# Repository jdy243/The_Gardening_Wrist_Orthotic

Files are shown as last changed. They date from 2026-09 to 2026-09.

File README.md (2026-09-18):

# The Gardening Wrist Orthotic

A student designed product for people whose wrist or joint pain gets in the way of gardening. Featuring a 3D-printed customized wrist brace and gardening glove. The brace supports the wrist and forearm, and a quick-release clip on the palm lets a hand tool click into place instead of having to be gripped. This Project was nominated & presented at the Buckeye Engineering Design Showcase, April 28, 2026, Ohio Stadium.
<br>
<br>

<p align="center">
  
</p>

<p align="center">Buckeye Engineering Design Showcase, April 28, 2026, Ohio Stadium.</p>

## Final Design
- [Physical Design Overview](https://github.com/user-attachments/assets/03434787-c6b2-4d2d-ab97-b5e6720f0fb0)
- [3D Model of the Brace](https://sketchfab.com/models/580d400f9824445db32a312051443653/embed?autostart=1)
- [3D Model of the Quick Release System (Adapter)](https://sketchfab.com/models/04e7fd2b0e794eb98720fba45b6b7ad8/embed)
- [3D Model of the Quick Release System (Base Plate)](https://sketchfab.com/models/98bdad573c1f4930803acb94b18789f5/embed)

### The problem

Weeding, digging, and turning soil put real strain on the wrist and forearm, especially for gardeners with arthritis or other joint pain. Most existing products only solve part of this: a wrist stabilizer supports the joint but doesn't help with gripping a tool, and compression gloves or ergonomic tool handles don't address wrist overextension. Products that do both tend to be expensive or bulky.

#### How it works

The brace is CADed based on the surface details from a user's hand model from a LiDAR scan, and later 3D printed in 95A TPU so it's shaped to that hand rather than a generic size. It's sewn onto a standard gardening glove and closes around the wrist with Velcro straps. A slot-clip printed into the palm of the glove locks onto a matching clip on an adjustable Velcro strap that wraps around a tool's handle, so the tool stays attached without needing a tight grip. All 3D-printed parts use hexagonal cutouts and a gyroid infill to keep weight down without giving up strength.

### Specifications

| Metric | Value |
| --- | --- |
| Total weight | 0.55 lb (254 g) |
| Load-bearing capacity | tested to 25 lb |
| Wrist flex range | 0-90 degrees (overextension blocked) |
| Time to put on / take off | 8.65 s (target under 50 s) |
| Time to attach or detach a tool | 4.3 s (target under 40 s) |
| Material cost per unit | $14.83 |

### The Team

Team N, ENGR 1182.01, The Ohio State University, advised by Professor Jergens.

- Jonathan Yang
- Riya Shankar
- Nicholas Farley
- Dawson McMurry

Presented at the Buckeye Engineering Design Showcase, April 28, 2026, Ohio Stadium.

# Repository contents

- [Technical Design Review](docs/Technical-Design-Review.pdf) — the full project report, covering problem definition, user research, concept development, prototyping, and testing.
- [Poster](media/Poster.jpg) — the showcase poster.

This repository currently holds the written documentation and poster. CAD files/3D-print file are on an alternative website; if you need them, you can download them though the 'Final Design' portion in README.

## License

No license file is included yet. Since this is a four-person team project.

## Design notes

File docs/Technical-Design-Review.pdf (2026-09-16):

# Gardening

# Wrist Orthotic

## Team N

### Riya Shankar

### Nicholas Farley

### Jonathan Yang

### Dawson McMurry

## ENGR 1182.01 7440

## Professor Jergens

## April 19, 2026

## Table of Contents

## Executive Summary

## Problem Definition Review

### 1. Introduction

Chronic and temporary joint pain affects a large demographic of people around the world. It stops individuals from participating in hobbies and activities of personal enjoyment and increases their intake of medication for pain relief. All members of Team N were tasked with interviewing an individual about frustrations they may encounter in their daily lives; some of their pains included poor house heating, laptop battery life, lower-back mobility issues, and joint pain while gardening. In this project, Team N has decided to address this problem for individuals who garden, whether professionally or as a hobby, and create a wrist orthotic device to stabilize the wrist and remain adaptable for gardening purposes.

The team has researched the demographic most affected by joint pain, the main contributors to such pain especially in the upper limbs, and alternative products on the market that are targeted toward solving the team’s chosen problem. The team created a graphical user persona to mimic the target audience of the project’s final product to solidify the intended users, and therefore also determine the most significant factors the team must take into consideration during the product brainstorming process. The team then compared alternative products to their own idea using informational graphics and charts and determined the user needs, factors, and costs required to create this product and ensure its effectiveness surpasses those of the alternatives.

During the brainstorming process, the team created three concept designs for the final product. The team considered the most effective methods of designing and creating the product, taking items like materials, budget, and user needs as the highest priorities. The team also received feedback from other teams to finalize the concept plan for the orthosis. The wrist orthosis will contain a brace around the forearm, wrist, and palm, and will be customized to each user using modeling software. A gardening glove with flexible support plates through the backhand and fingers will be attached to the brace, allowing users to garden comfortably. A quick release plate will be sewn onto the palm of the glove to correspond with another plate attached to an elastic band that can be put on the handle of hand shovels and small gardening tools. The plates will click and attach to provide the user with a firmer grip upon the tool and subsequently further relief on the wrist and joints.

### 2. Problem Definition

The problem the team aims to address is the lack of accessible assistive devices that allow individuals with joint pain to garden comfortably and safely. The team is exploring the design of an orthosis or similar product intended to reduce pain and strain during gardening activities. The selected user group includes individuals with upper-body joint pain and mobility limitations, caused by either chronic or temporary illness and injury.

a. User Persona

Figure 1 depicts the team’s user persona, named Riley Thomas, who represents a potential individual within the team’s selected target audience. Riley is a 65-year-old Caucasian American woman who lives with her husband in a suburban neighborhood. She has a college education, is currently retired, and frequently gardens in her front and backyard. She has arthritis that especially affects her wrists, elbows, and shoulders, and she often takes medication for pain relief although the medication may have long term effects on her body.

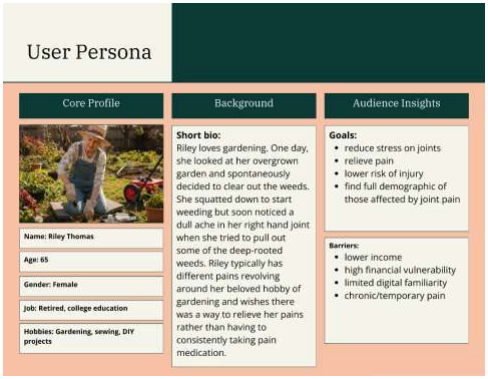
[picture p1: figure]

Figure 1. Graphical User Persona

Riley loves gardening. One day, she looked at her overgrown garden and spontaneously decided to clear out the weeds. She squatted down to start weeding but soon noticed a dull ache in her right hand joint when she tried to pull out some of the deep-rooted weeds. Riley typically has different pains revolving around her beloved hobby of gardening and wishes there was a way to relieve her pains.

b. Tasks and Pains

The selected user group has a considerable number of tasks and pains associated with gardening while affected by joint pain. Common gardening tasks include weeding and planting on the ground, forcing individuals to bend and rest on their limbs often. Additionally, digging and turning soil requires the use of heavy tools and repetitive motions that can strain arm joints and may require often taking medicine to relieve pain.

- Task: Weeding and planting

- Pain: It requires constant, forceful, use of hands and forearms.
- Pain: It often requires resting on the arms and elbows.
- Pain: It is difficult to reach the roots of the weeds buried in the soil.
- Pain: It is often necessary to take many breaks and take pain relief medication.
- Task: Digging and turning soil
- Pain: Using shovels can put severe strain on the arms.
- Pain: Can cause tendonitis & carpal tunnel syndrome from gripping tools tightly.
- Pain: Can strain the rotor cuff due to repetitive actions.

### 3. Research Plan

The goal of conducting research is to gain an understanding of what the most common factors of joint paint and mobility issue plague individuals to have a basis for the anatomical nature of the team’s product. Another goal of the team’s research is to learn how to design such a product, particularly using three-dimensional modeling software, what materials are needed to build the product, and how the product can be more efficient compared to other similar products in the market. An ethical consideration the team discussed was the environmental concerns that come with using plastic for the basis of the product, and the team’s solution to this is using recyclable filament during the 3D printing process.

Table 1. Research Plan Table

Research Question | Qualitative Data Collection | Quantitative Data Collection
(RQ1.1) Which upper-body joints or anatomical parts are largely affected by joint pain? (RQ1.2) What is the demographic of those affected by joint pain? | Online research paper of pain mapping for common shoulder disorders [1]. | Online article of a survey study of upper limb pain and disability among university students [2]. Online research article the changing profile of joint disorders with age [3].
(RQ2) What are the common tasks and pains associated with gardening? | Online article and study that characterizes gardening tasks and corresponding body positions done by older adults. [4] | Online research article on hand discomfort among gardeners. [5]

(RQ3) What are orthoses and how do they provide structural support? | Online article covering how different orthotic devices or orthoses are created and used to benefit the users whether they are stabilizing or preventing injury. [6] Online article that lists and explains the different strategies and components in making an orthotic/prosthetic device. [7, 22] | Online article representing the results of a survey where participants were prescribed an orthotic device in which the average score of the participants satisfaction of the device was 4.53/5. [8]
(RQ4) How can 3D modeling be used to create a product? | Online article comparing traditional and additive manufacturing processes and how 3D printing offers potential in developing orthotic devices [9]. | Online article showing the effectiveness and quick fabrication process of 3D printed orthotics and prostheses in canine, proving the viability of these products in the medical field [10]. Online research article showing how effectively utilizing CAD and 3D printing technology can manufacture smaller and lighter medical products [11].
(RQ5) What are some other similar products that solve this problem, and how can our product be more efficient? | Online research paper on improving gardening for people with arthritis. [12] | Online conference paper covering orthotic prototypes for patients with osteoarthritis, chronic joint pain. [13]

### 4. Research Results

a. Creating User Value

Pains

Gardening is undoubtedly a taxing process on your joints, making it harder for some older or injury-prone people to grip tools and have a proper range of motion for the activity. Some orthotic prototypes have already been developed such as an ergonomic chair [12], yet these solutions are big and unpractical in everyday, gardening use. Researchers analyzed a group of older gardeners, after performing seventeen different common garden tasks, over ten different pains were observed, demonstrating the risk and damage caused by the consistent, scooping, bending, and stretching of the joints and ligaments during gardening [4].

- Using shovels can put severe strain on the arms.
- It can cause tendonitis & carpal tunnel syndrome from gripping tools tightly.
- It can strain the rotor cuff due to repetitive actions.
- Gardening requires constant movement, getting up and down, and frequently resting on elbows
- Can lead to pulled and torn muscles in the arms

Gains

Different 3D printing processes can allow manufacturers and the team to construct different orthotic devices at a quicker pace at a lower cost. It can allow the team to create a model where the team can print 3D parts with different types of filaments that can be changed for different needs. Such as carbon fiber laced filament for durability or TPU for parts that need to be flexible. [9].

- More efficient
- Will take less time and effort to pull weeds out of the ground
- Lower consumption of pain medication
- Rely less on pain medication, reducing their spending
- More cost effective (user only needs one tool instead of multiple shovels, etc.)
- The device will be cheaper than other orthotics on the market
- Adaptive; can change the tools out
- Users can attach gardening tools that can be interchanged on the device

User Needs

Orthotic devices help the users' needs of reducing pain and having a lower risk of injury by allowing the joints, muscles, and bones to be more structurally sound and stable [6]. The overall goal of this device is to aid and target users with joint pain, ensuring several design requirements/categories are met (cost, pain reduction, etc.). For example, pivoting the orthotic device in a 3D printing direction not only makes production faster, but it is cheaper and more adaptive. Additionally, with recyclable filaments, an eco-friendly approach to orthotics could also be explored [10].

- Performance Efficiency
- Pain Reduction
- Lower Risk of Injury

- Cost-effective
- Adaptive
- Comfortability
- Durability

Pairwise Comparison Chart

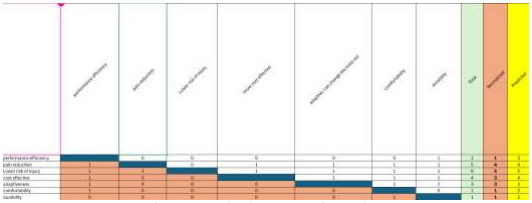
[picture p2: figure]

Figure. 2. Pairwise Comparison Chart

With any design process, some users need to become more redundant over time as design focus shifts from idea to idea. As shown by the above comparison chart, needs such as efficiency and durability were only preferred by the team once over other categories, while needs such as pain reduction and injury prevention were more heavily prioritized in the team’s brainstorming and development process [14]. While searching for other orthotic devices, the team noticed that most wrist-hand orthotic devices also couldn’t balance certain needs when designing, including more commonly cost versus durability and effectiveness. With this as the team’s priority, some sacrifices to the final prototype may need to be made, however it is a matter of balancing the needs than homing in on only a few needs [25].

b. Market Character

Stakeholders

- Medical Orthotic Companies
- These companies could invest in these orthotic products, possibly being able to work with the team to bring these devices to a wider market.
- Urgent Cares/Medical Centers
- These facilities could buy and distribute them to patients in need when properly consulted by a physician.
- Medical Stores/Pharmacies
- The team can easily sell and distribute these products nationwide through stores like CVS, Walgreens, etc.

Market Size

The global market for wrist-hand orthotics is already growing at a rapid rate, currently sitting at around 1.8 billion USD in market cap, with a projected 3.1 billion USD market cap by 2033 [14]. Additionally, Wrist Supports Market size was valued at USD 1.5 Billion in 2024 and is forecasted to grow at a CAGR of 7.2% from 2026 to 2033, reaching USD 2.8 Billion by 2033 [15]. With a growing market, there are more target users. The team’s device will be used by general wrist-hand orthotic patients but mainly targets users who want to work hands-on, in this case gardening, with their orthotics. The main idea for the team’s device is to allow users to complete their daily tasks without unbearable joint pain and with the associated attachable tools, hands-on activities like gardening/weeding are performed with ease.

Current Alternatives

- Strap Wrench: Tool that uses a rubber or nylon strap, typically 12–18 inches long, to grip smooth, polished, or irregular surfaces [20]
- Twist Jar Opener: A handheld or automatic kitchen tool designed to easily remove jar lids that are stuck or stubborn [19]
- ACE Carpal Tunnel Wrist Stabilizer: Wrist brace; “Stabilizer helps relieve symptoms associated with Carpal Tunnel Syndrome with superior, stabilizing support” [18]
- IMAK Compression Gloves: Specialized gloves designed to relieve hand pain, stiffness, and swelling associated with arthritis and poor circulation by tightening around the joint [23]
- PenAgain: Ergonomic pen; “This wishbone-shaped writing utensil is designed for those with carpel tunnel, arthritis, and anyone with a weak grip or limited grasp. It allows the pressure of the natural weight of your hand, rather than your grip, to guide the writing instrument.” [21]
- Paexo Wrist: Mechanical skeleton brace; “Paexo Wrist provides effective support for your wrist when handling loads. The exoskeleton was derived by Ottobock Industrials from a medical device that was specially developed for the treatment of wrist inflammation.” [17]
- Daiya Wrist Exoskeleton: “The Daiya wrist exoskeleton increases support to your wrist during load and tools handling. Its thin aluminum support adjusts the level of wrist fixation in stages to reduce pressure, and three pockets containing aluminum supports on the back and palm of the hand allow the user to adjust the level of fixation.” [25]

- Stainless Steel Tongs: Multipurpose tongs: “Stainless steel construction: these tongs feature a high quality, 430-stainless steel frame” [24]

Figure. 3. Current Alternatives Comparison Chart

Some gaps that the team noticed between the current alternatives are that many of them focus on being cost effective while sacrificing other important aspects such as durability and adaptiveness. The team concluded that the goal would be to try to create a device or product that includes most, if not all, of these attributes to ensure that the product will remain a reasonable price while also allowing it to be durable and adaptive for different uses.

In a survey conducted in 1997, about 30% of the respondents indicated “chronic upper extremity pain associated with physical impairment” [1]. Participants who experienced such pain were a demographic consisting of both men and women of ages 25 to 74 who were randomly selected, and were likely to be blue collar workers, long-term absentees, and current or former absentees. In corroboration with this source, another study conducted in 2019 resulted in a 24% respondent rate of the prevalence of upper limb pain [2]. This study’s subjects were university students between the ages of 18 to 28 where most subjects had been using smartphones for more than 5 years. The results of both studies show that chronic and temporary upper limb pain and discomfort are prevalent across a large demographic, and therefore the team’s decided target audience has not been limited to constricting age, gender, or ethnic range.

Hand tools, such as spades, shovels, sickles, and rakes, are commonly used by gardeners during activities. The excessive use of such tools is often followed by pain or discomfort in gardeners’ hands and forearm regions. Manual work such as gardening requires repetitive movements and can cause high muscular discomfort and strain injuries in the upper limbs due to forearm muscle strain and poor wrist posture. Findings of a 2024 study unveiled that majority of respondents found gardening hand tools to have low to moderate comfort, and there was an increase in pain and discomfort in the hands while using such tools which in turn interfered with their gardening performance [5].

An article published in 2022 showed that traditional orthotics/support devices (such as the spinal cord injury orthotics in this article) are usually made of plaster, and the advent of low-temperature thermoplastic sheets make the finished products bulky, time-consuming (1 week) and expensive [11]. At the same time, due to the limitations of the manufacturing process, their appearance is difficult to make aesthetically pleasing, and their geometric defects also lead to a lack of personalized comfort and functionality. However, by using 3D printing technology, people can design structures that are difficult to make by hand and have extremely high precision. Another study also showed that compared with traditional manufacturing methods, 3D printing technology can produce an orthotics/support device with personalized customization in terms of fitness and shape in one day, thus providing patients with a more economical, comfortable and personalized product [10]. Additionally, a study focuses on customized orthotics/prostheses also showed that it takes less than 6.5 hours to manufacture a 3D printed personal orthotics using PLA Material on a fused deposition modeling (FDM) machine, and the average operation time is only 10-15 minutes. Compared to traditional methods, the time required to fabricate orthotics for patients using 3D printing technology will be significantly shorter [9].

### 5. Value Proposition

The team’s proposed solution to address the problem of joint paint and mobility issues is designing a supportive brace or glove that can lower the user’s pain level. The product is specifically designed for gardening purposes, with the ability to attach tools to the brace that can help users easily weed and plant their gardens. The target end users are individuals over the age of 18 who suffer from temporary or chronic join pain specifically in the wrists. Since race or gender do not seem to define the demographic of those affected by joint pain [2] but typically adults or older aged individuals find themselves to be more affected [3] [4]. The team has decided to focus on developing the product for those in the age range of 18 and above. Users of this device will experience reduced joint pain and can swap out tools on their device, making strenuous tasks like shoveling or gardening less likely to inflict lasting injuries or pain. Being that this device is 3D printing allows it to be a cost-effective option for users, preventing unbearable joint pain without breaking the bank. With the growing market in these wrist-hand orthotics expecting to double in some regions by 2033 [14], this device will likely be revolutionary, all-in-one for those who want to be active without the worry of serious injury and pain.

### 6. Design Focus

The team has discussed and concluded that when it comes to the overall design of the brace, the team wants the product to be comfortable for the user. As a result, the team decided that the best options for securing the brace to the user would either be a Velcro type of function to ensure that the product will stay attached to the user comfortably without it pinching too tight or being too loose. Additionally, the team debated on including a feature of convenience such as utilizing a magnetic plate or an area with different straps that allow users to have easy access to different gardening tools without having to often bend to reach the ground or crowd their hands and pockets.

The team decided that the easiest way to design the product is through the Computer Aided Design (CAD) software. The team intends to produce the final product by 3D printing the base structure with filament, as the variety of filaments that can be used can be determined in context of the products need to be more flexible or durable [11]. These components can also help with the user needs the team identified because filament is environmentally friendly as it can be recycled and additionally, it can typically be stretched out for long distances for a cheaper price, allowing the team to market the product at a more cost-effective standpoint while remaining effective for use.

## Concept Development Review

### 7. Concept Brainstorming and Ideation

a. Process Description

When brainstorming new ideas for the design, the primary method for finding new design options was to research other orthotics, take inspiration from other protypes and designs, and rework them to fit the gardening orthotic. Another important factor when brainstorming is fitting user needs. When an idea is brought to the team, it is evaluated for how it applies to all the user’s needs. Big factors like cost, pain reduction, and injury prevention are focused during this process with other needs being secondary but still vital for the final design. Overall, the main process for the team’s concept of brainstorming is to research and compare user needs, finding the most viable and safe option for its users.

b. Brainstorming Results

The team concluded from brainstorming that the final product would focus on pain reduction and adaptiveness and therefore would include a kind of magnet or strap on the palm of the orthosis to attach different gardening tools to the structure. One possible idea discussed for this detail was 3D printing a quick-release clip slot sewn or in some way attached to the palm of the orthosis glove and additionally create a strap with a slotting piece that could be wrapped around any tool. The slotting piece could be inserted into the clip slot on the glove, allowing the user to gain a firm grip on the tool while being able to easily remove the tool. The team discussed methods that could be used to adjust the sizing of the orthosis, such as Velcro, string, or a quick lacing system using turn knobs. The team decided that the lacing system would be rather difficult to implement and deemed Velcro the better solution. For the base structure of the orthosis, the team considered using a fabric compression glove for the palm and fingers and utilizing 3D printing for the wrist brace structure, which could be customized to the user using an online modeling software such as Lidar Scan.

### 8. Concept Selection

a. Down-Selecting to Two Concepts

Through the team’s discussions with other teams, the team was able to pick two final concepts as to what the team’s product would include. Many of the other teams liked the idea of a quick-release plate for adaptability as well as the team’s idea of how the team was going to secure the device on the user. The two remaining concepts (concept 1 and
2) were selected because both included useful and worthy additions. For the team’s final product, students will most likely combine the best aspects from both concepts to achieve the best overall product.
b. Pugh Scoring Matrix

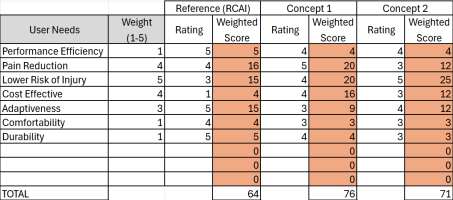
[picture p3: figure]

Figure. 4. Pugh Scoring Matrix Chart

These results show that the reference design (RCAI Wrist Orthotic), while being superior in some categories, struggled to meet user needs like cost effectiveness and lower risk of injury, two important user needs for the final design. The two concepts, however, are far superior in terms of price relying on 3-D printed materials and fabrics and focus more on preventing further injury by providing ample support to the wrist and possibly finger joints. Unfortunately, due to the restrictive durability range of TPU filaments, the prototype will most likely be less durable than the reference orthotic, however being that durability isn’t as important for the final design, these small flaws can be overlooked for the most part as the team focuses its design on effectiveness and cost.

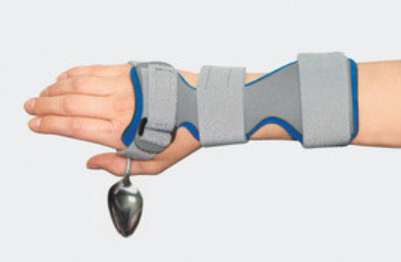
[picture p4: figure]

Figure 5. RCAI Wrist Drop Orthosis [26].

c. Final Concept Selection

The final concept selection will not be based on a specific concept, but rather on combining the advantages of both Concept 1 and Concept 2 due to them both scoring a similar score (5-point difference). Both designs have some drawbacks. For example, the complex locking design of Concept 2 will lead to increased costs, while the installation tooling method of Concept 1 is not as efficient as that of Concept 2. This will allow the team to create the most efficient product by combining the best aspects of our previous sketches, resulting in a product that should be able to fit most the user’s needs.

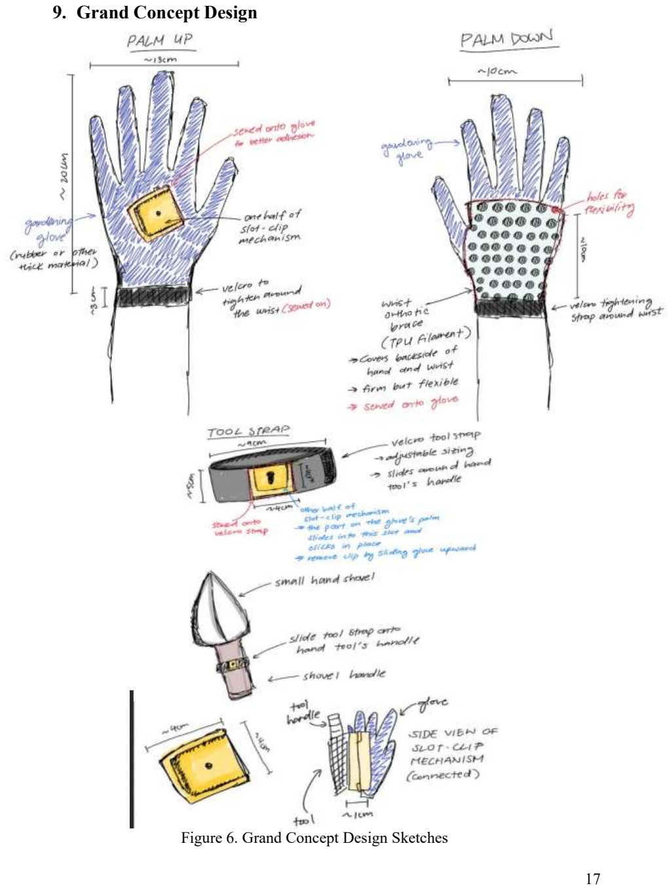
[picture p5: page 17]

### 9. Grand Concept Design

Figure 6. Grand Concept Design Sketches

The grand concept design of the team’s product is a wrist orthosis that consists of a fitted brace (green brace with cutouts) for the forearm and wrist, a glove with thin metal supports running through the seams (dark blue glove), an attached clip on the palm of the glove, and an elastic band with the other half of the clip (pink band) that acts as a slotting mechanism. For demonstration purposes, the team has created a mockup cardboard shovel to show how the elastic band would be able to slide onto the handle of a small hand shovel.

The user would interact with this design by inserting their hand into the brace and glove, with the glove resting underneath the brace structure. The glove provides support to the wrist as it has strips of metal running through pockets on the inside of the glove. These supports are located on the backside of the glove. The brace will be fitted to the user using 3D modeling and will provide tight, secure support to the forearm and wrist. The elastic band will slide over the handle of a small hand shovel or tool. The clip on the elastic band will slot into the clip on the palm of the orthosis and stay in place. The user will be able to remove the clips from each other by pulling upward on the elastic-band clip, releasing it from the slot. The size of the design would be approximately big enough for an adult forearm. The team’s intention with this product is to customize it personally to each user rather than utilize one-size-fits-all dimensioning. For this concept, the orthosis is modeled for a young adult male.

The features that make this design unique are the adaptability of its usage. The elastic band can be fitted onto many hand tools besides gardening tools, and the brace will provide support regardless of whether the user is using the product for a task or simply providing pain relief and compression. The anticipated challenges of developing this idea into a fully realized product are ensuring the comfortability and practicality of the design. As the team’s priorities include efficiency, a challenge would be to ensure that the metal support strips do not prod the user’s skin and provide support without breaking easily, remaining comfortable on the user’s skin.

Additionally, another anticipated challenge is ensuring the clip can support the weight of a hand shovel. To confirm its viability and to gain traction in the market, the design must be versatile as this was the most common value that other products on the market lacked. To prove this, the elastic band must be able to fit over a variety of hand tools besides gardening tools, and the clip must work to secure the orthosis to the elastic band in each case. The product must also be able to relieve users’ pain by means of support and compression across the palm, wrist, and forearm as this is the best way to test its effectiveness.

### 10. Prototyping Design

a. Description of Prototype

Team N plans to design and create a fully functional wrist orthotic for those who are active with hand tools and gardening instruments, reducing joint pain and preventing further injury. The brace is created based on a Surface scan (LiDAR) of a real human hand [27]. This orthotic will slip on like a glove with a rigid, weight-bearing 3D-printed support (brace) that hugs the back of the hand; this will be sewn on to provide better durability. To wear it, the user will insert their hand into the gardening glove through the pinky-finger side of the glove; the user can close the side of the glove using a Velcro strip that runs along that side of the glove. The orthotic can then be secured using Velcro straps located at the wrist, ensuring the glove will not slip off ensuring use. In addition, a 3D-printed slot-clip is sewn into the palm of the orthosis and using a provided tool clip strap, a second slot-clip can be placed on most gardening/hand tools using an adjustable Velcro strap. When slotted into each other, the tool becomes fully fastened to the orthotic meaning the user doesn't need to strain their finger and wrist joints when gripping the tool and with the rigid support on the back of the glove, overextension of the wrist is prevented. When prototyping, budgeting and meeting our user’s needs leads to the biggest limitations, scaling down previous ideas and overall simplifying the team’s concept, however, with the access to 3D printers, Team N can explore more complex support designs and mechanisms allowing for design complexity at a low budget. Team N intends to use OSU’s EED store to order parts such as Velcro and 3D prints and use OnShape to model testing of the orthotic.

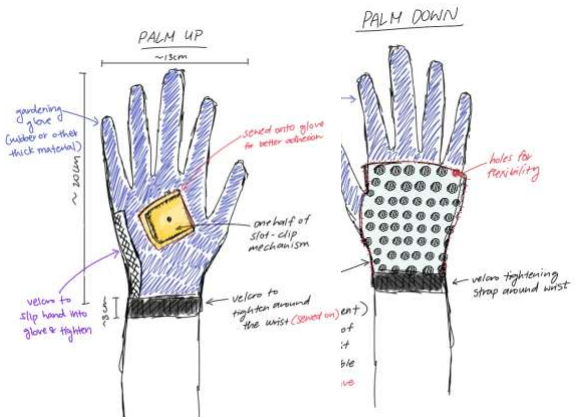
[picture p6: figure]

Figure 7. Wrist Orthosis Prototype Sketches

Figure 8. Slot-Clip Mechanism and Demonstration Sketches

b. Prototype Design Requirements
Design Requirement | Range of Values | Ideal Value | Design Process | Correlating User Needs
Time taken to put orthosis on | 20-50 seconds | 20 seconds | Test ease of putting on and taking off the orthosis during design process | Adaptiveness
Holds tools up to 10 pounds | 1-10 lbs. | 10 lbs. | Attach weights and test durability | Durability, Performance Efficiency
Prevents over-extension of wrist | Wrist can flex 0-90 degrees | Doesn’t extend past 90 degrees | Consistently try on prototype and check wrist flexibility | Pain Reduction, Lower Risk of Injury

Fast slot-clip mechanism | 10-40 seconds | 10 seconds | Time how long it takes, change sizing of parts if necessary for smoother process | Performance Efficiency, Adaptiveness
Low weight | 1-2 lbs | >1.5 lbs | Consistently weigh the prototype | Cost Effective, Comfortability
c. Testing Methodology and Verification Plan

To properly test and verify the design requirements for the prototype, a series of different strength, durability, and logical tests will be performed. To start, a simple load bearing test will be performed on the clip, the team wants to ensure that the quick-release system can hold up to 10 pounds of additional weight without slipping or breaking. To do this, the team will attach different weights (ex. dumbbell) to the quick-release system starting at 2.5 pounds and increasing up to 10 pounds to gradually stress testing the entire system. This process will repeat three times. Additionally, during all three testing processes, students will try to observe (ex. sound) and inspect for deformations or weak points within the system as testing occurs to ensure durability remains constant.

With the gardening wrist orthotic remains on, the team will also ask the user to bend their wrist back and forth to ensure the grading glove braces their wrist and prevents it from overextending or bending, which helps to prevent further injuries. The user will repeat this process five times to ensure its reliability and efficacy. These trials will be measured using a protractor, measuring the wrists’ angle and seeing at what point it stops. Additionally, the gardening wrist orthotic will be weighed to ensure it remains lightweight, targeting under 1.5 pounds to avoid additional force on the user’s joints.

Next, the orthotic will then be tested for ease of use and transfer on and off the user’s hand. Using Team N members, each member will be timed for how long it takes to get the gardening wrist orthotic on and off from their hand, as well as how long it takes to attach and detach the tool onto the quick-release system’s adapter. They will each be timed three separate times with their times averaged, with the team targeting a 10-second average. This is done to make sure the device is easy and adaptable to almost all users, making it a more accessible product to a broader market.

Finally, when finalizing the gardening glove, the team will create and manage a budget to ensure that the orthotic is cheap and efficient to make, utilizing processes such as 3D printing and minimizing materials for a cheaper and simpler design.

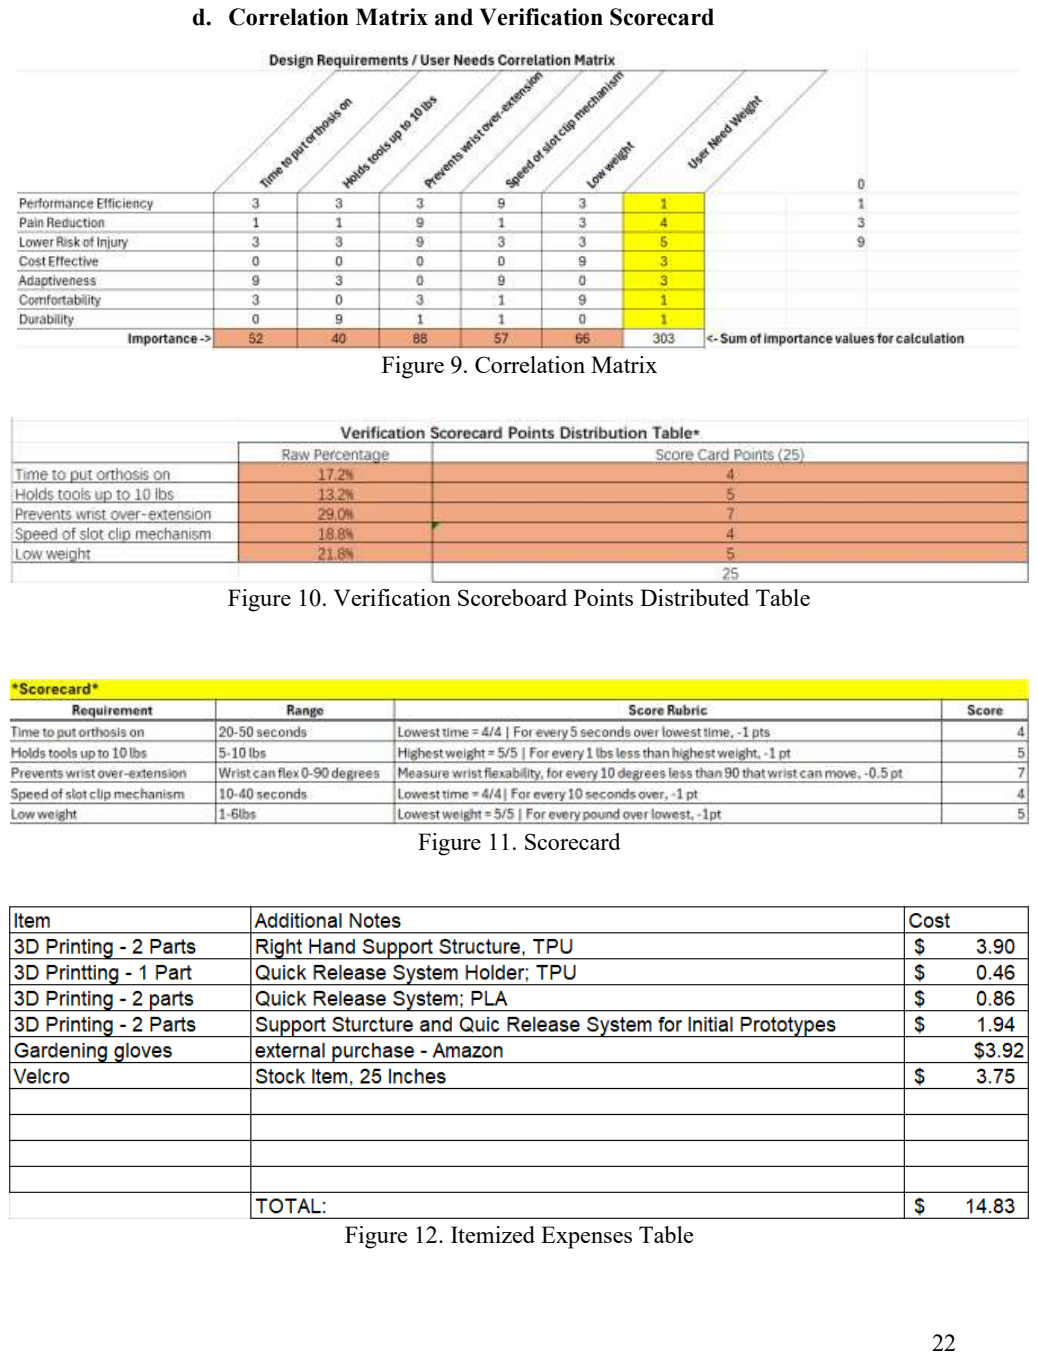
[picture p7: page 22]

d. Correlation Matrix and Verification Scorecard

Figure 9. Correlation Matrix

Figure 10. Verification Scoreboard Points Distributed Table

Figure 11. Scorecard

Figure 12. Itemized Expenses Table e. Protype Preliminary Design and Mock-up

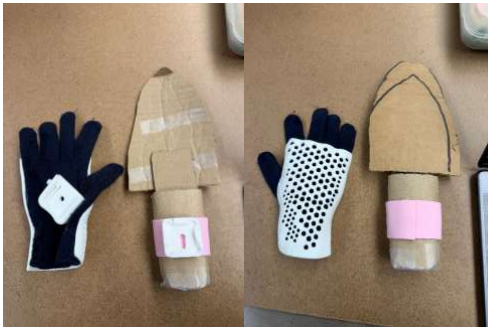
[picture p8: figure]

Figure 13. Wrist Orthotic and Tool Attachment Mock-ups

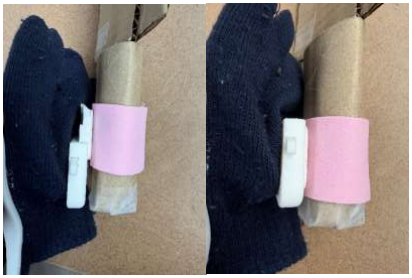
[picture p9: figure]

Figure 14. Slot Clip Mock-up Demonstration

During the creation of the mockup, the target design became clear to the team. An important change was made, switching from a magnetic clip to a 3D-printed clip system to maximize grip on the gardening tool. Utilizing a clip system ensures that the tool is securely fastened to the orthotic and it also makes the development process easier, as the clip design can be modeled in CAD software to fit the specific orthotic dimensions rather than modeling around them during the 3D modeling process and setting in magnets after. Additionally, when creating the mockup, Team N decided to exclude the original design’s finger supports, making a fingerless orthotic design as most of the joint pressure is directed on the wrist when using tools. This change makes the design cheaper and more accessible to a wider market allowing more dexterity for the user.

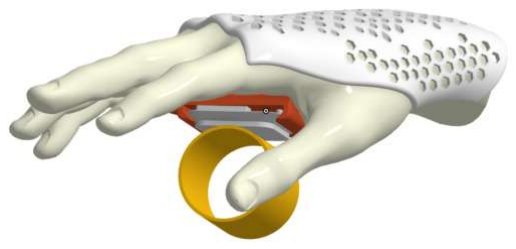
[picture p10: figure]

Figure 15. Sample Wrist Orthotic CAD Assembly

## Detailed Design Review

11.Prototype Fabrication and Evolution

From concept to physical prototype, Team N’s “Gardening Wrist Orthotic” utilized simple fabrication processes like 3D printing to create both a flexible support system for the back of the hand as well as a clip/slot system designed to secure tools to the palm of the orthotic. For the main part of the orthotic, Team N used a standard gardening glove, adhering the base clip to the palm using super glue and sewing the back-hand support to the back of the glove. Subsequently, Team N noticed that it would be nearly impossible for the user to slide their hand in the glove given the 3D-printed support hugs the wrist. To fix this, the side of the glove was cut open along the pinky side, allowing the user to fit their hand into the glove, three Velcro straps were then added on the glove, equidistant from each other, the loop side of the Velcro placed on the 3D-printed support, allowing the user to close the opening made from the cut and tighten the orthotic around their hand/wrist. Assembling the tool clip, Velcro was adhered to the 3D printed clip using super glue, formed in an adjustable loop that can be tightened to the desired circumference of the tool handle.

From here, the orthotic began its preliminary testing including a weight-bearing test, several speed tests, a wrist-extension test, and a measured test of the orthotic’s overall weight. The team used OnShape to simulate a load-bearing test on the clip by applying loads up to 10 pounds on the base clip, checking for deformations or failure after each trial. As a result, the clip system survived each trail with little to no changes, proving to be a durable clip design. Next, the team tested the speed of equipping the orthotic as well as the speed of the clip system. To do this, each member was timed putting on and tightening the orthotic, then in another test they were timed for how long it took to attach and detach a tool from the clip system. The resulting times were much less than initially expected, with the average time of these tests both being under 10 seconds, less than the expected time ranges for the trials as well. Testing the wrist overextension protection, each member put on the orthotic, bending their wrist back as far as the orthotic allowed, using a protractor to measure the wrist’s angle. After every member was tested, all trials showed success in preventing the user from extending their wrist past the targeted 90-degrees, lessening the risk of further injury on the joints. Lastly, the orthotic was weighed, clocking in just under three pounds, maintaining its lightweight design while reducing additional strain on the user’s hand caused by the orthotic.

After preliminary testing was complete, Team N decided that some initial design features would not need to be added to the final prototype, including metal strips that would slide between the support and the glove, providing additional rigidity to the orthotic support. Given the success of weight-bearing tests, the team concluded that the 3D-printed support would suffice, providing ample weight-distribution, reducing strain on the user’s joints. On the other hand, the team added black electrical tape on the Velcro straps, cleaning up the orthotic for a sleeker design while also providing additional grip on the tool clip and the palm of the orthotic given the rubber-like properties of the tape.

12.Detailed Design

a. Final Prototype Design

Team N’s final prototype design matches the team’s research conducted in the beginning stages of the orthotic’s development. As concluded from the research, the main joint pain caused from gardening is in the wrist joint, which is explicitly targeted by the Gardening Wrist Orthotic to resolve pain and lower the risk of further injury. Additionally, as other products on the market that relate to relieving joint pain lack adaptability, durability, and comfort, Team N strived to design the Wrist Orthotic to resolve these issues for the end users and create a product better than those present in the market. The team has designed non-standard parts to address and rectify such lacking details. The possible customization of the wrist brace makes the orthotic unique in its ability to be tailored to individuals, providing comfort. The slot clip mechanism is another non-standard part designed to improve the efficiency and adaptability of the orthotic by allowing the user to gain a firmer grip upon hand tools while gardening and having the ability to be resized and adjusted to many different handle sizes using Velcro.

Future design considerations include simplifying the brace design to allow for easier 3D modelling in the OnShape software and potentially shifting to a more versatile modelling software. Some anticipated differences between the current prototype and the final product may account for a more elegant look with improved materials rather than the reliance upon cheap, unattractive materials – for example, using fabric or molded plastic rather than the electrical tape currently being used upon the slot clip band.

Figure 16. Final Prototype Design of the Gardening Wrist Orthotic

b. Revised Grand Concept Design

All 3D-printed components designed by Team N features weight-reducing cutout patterns (specifically, regular hexagons)—a design choice made to find a balance between the overall weight of the Gardening Wrist Orthotic and its structural integrity. The team noticed that these hexagonal cutouts significantly reduce the weight and printing costs of the 3D-printed parts (the brace and the Quick Release System) while ensuring that the components maintain a robust load-bearing structure. Furthermore, the team also learned that a gyroid internal printing structure provides maximum structural rigidity while simultaneously reducing weight. So, the Quick Release System itself was revised from its originally envisioned 100% infill density to a 50% infill density, with the internal printing structure changed from lattice to gyroid, during the 3D printing processes.

Additionally, during the prototyping phase, the team opted to eliminate the internal metal support that stays within the glove. This modification was implemented after the initial testing revealed that the glove provided support exceeding the team’s expectations, even when relying solely on the TPU 3D printed brace as its structural support mechanism. Furthermore, removing the internal metal allows enhanced user comfort while wearing the Gardening Wrist Orthotic.

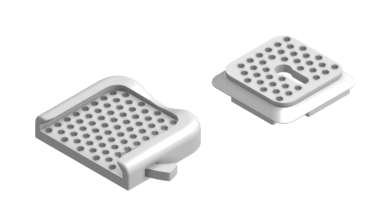
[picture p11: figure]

Figure 17. Quick Release System w/ Weight-Reducing Patterns

13.Final Prototype Verification

14.User Validation

Team N’s three most important identified user needs are adaptivity, lower risk of injury, and performance efficiency, as referenced from the Pairwise Comparison Chart. The team’s user validation plan to determine how well the final design of the orthotic solves the indented problem and meets the top user needs is through consistent testing and utilizing user feedback. The team will ask three individuals who fall under the target audience demographic – individuals over the age of 18 who experience temporary or chronic upper limb joint paint – to try the prototype orthotic. The team will record any given improvement advice after conducting the following tests and ask for user feedback after their experience with the orthotic to gather raw data:

1. Time how long the user takes to put on and take off the orthotic.
a. If the time exceeds 50 seconds, the prototype does not demonstrate performance efficiency.
b. If the recorded time is less than 50 seconds, the test is passed.
2. Time how long it takes for the user to put on, use, and take off the slot clip mechanism.
a. If the time exceeds 40 seconds, the prototype does not demonstrate performance efficiency nor adaptability.
b. If the recorded time is less than 40 seconds, the test is passed.
3. Measure the angles at which the user’s wrist can freely bend.
a. If the user’s wrist can bend past 90 degrees backwards, the prototype does not provide a lower risk of injury.
b. If the recorded degree of movement does not exceed 90 degrees, the test is passed.
4. Ask the user if they think the orthotic is comfortable or uncomfortable.

a. If the user responds that the orthotic is uncomfortable, the prototype does not lower risk of injury, nor can it function as a competitive product on the market.
b. If the recorded response is “comfortable”, the test is passed.

If all three users’ tests pass successfully, then the prototype will be determined as having full user validation. Otherwise, the team will continue to improve the orthotic before asking for user validation once more. The team will continue to improve, conduct trials, and ask for feedback until all three users’ tests pass.

Regarding the ethical considerations associated with collecting personal information during such trials, the team members will address each user with respect and will conduct all trials fairly, equally, and without bias. The users are not required to participate if they choose not to. Users will be given the choice to have any personal information such as their name, gender, age, and any other demographically significant detail to be recorded or not.

15.Value and Impact

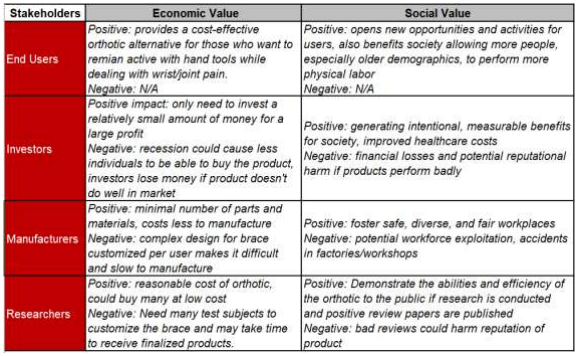
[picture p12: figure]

Figure 17. Value Matrix

Stakeholders are individuals and/or organizations with an interest or concern in the design, development, and marketing of the Gardening Wrist Orthotic. The orthotic’s most significant stakeholders are end users, investors, manufacturers, and researchers. The respective value categories that affect each of the stakeholders include economic and social impacts.

The positive economic impact upon end users is that the orthotic provides a low-cost alternative product for those who wish to remain active in using hand tools while dealing with wrist and joint pain. The team concluded that there were no negative economic impacts upon end users as the orthosis is marketed at a low cost. The positive economic impact upon investors is that such individuals or organizations would only need to invest a relatively small amount of money in the development and creation of the product in return for a large profit. However, the negative impact upon investors is that potential recession could cause a loss of the public’s ability to buy the product, causing investors to lose money if the product does not perform adequately in the market. The positive economic impact upon manufacturers is that only a minimal number of parts and materials are required to create the orthotic and therefore reduces manufacturing costs, but conversely, the complex design of the 3D printed brace which is customized per user makes it difficult and slow to manufacture. Lastly, researchers could spend a reasonable amount of money to buy and test the orthotic for research purposes, but in turn researchers would require many individuals to customize the brace, causing a slow manufacturing and return process.

Team N has determined a balance between revenue and costs for the orthotic. Since the cost of manufacturing remains relatively very low, the team has decided to market the product at a price double the cost of manufacturing to ensure profits. The product will likely be self-sustaining as it was designed to be durable, and any required subsidies will be sold at a low cost to allow a large target audience to be able to purchase the
product. Anticipated start-up costs will likely be expensive because 3D printers, filaments, and any required non-bulk material can be costly. Operating costs may also be rather costly as creating the CAD models for each customized brace will require a significant amount of time and experience. Forms of potential revenue will likely come directly from end users in the form of digital currency as the orthotic will only be available for purchase online. Possible subsidies required for socially focused solutions include workforce development, de-risking instruments, and program-related investments to continue funding the production and manufacturing of the orthosis.

The positive social impacts upon end users include new opportunities and activities available and allowing more individuals, especially those in the older demographic, to perform more physical labor for entertainment or professional need. There are no negative social impacts as the goals of the orthotic are to lower users’ risk of injury and provide support to the wrist joint. The positive social impact upon investors are generation intentional, measurable benefits for society along with improved healthcare. The negative impact includes potential reputational harm if the product performs badly. The positive impact upon manufacturers includes the ability to foster safe, diverse, and fair workplaces, while the negative impacts upon this stakeholder are potential workplace exploitation and the risk of accidents at manufacturing sites. Finally, the positive social impact upon researchers is their ability to demonstrate the orthotic’s efficiency to the public and publish positive review papers in its favor, boosting the orthotic’s sales while reaching a larger audience. The negative social impact upon researchers is the possibility of bad reviews that could harm the product’s reputation and/or possible bias when conducting research upon the wrist orthotic.

Some potential unintended negative consequences of the team’s solution on society or the environment include excessive filament waste when 3D printing the brace and slot clips, as support structures may not always be recyclable and often, recyclable filament itself can be costly. The required sanding, frequently required testing, and potential failed prints may rack up production costs. Additionally, the brace may not provide the exact support every individual user’s needs as such joint pains can be arbitrary and inconsistently afflicted upon the user, causing the brace to be a general solution rather than an extremely targeted one. Since the team is utilizing scanning software to shape the brace for each user, the scans may not be perfectly accurate for the user and may require multiple trials, increasing the time the end user must wait for their order to be completed.

16.Project Recommendations and Next Steps

## References

[1] Gummesson, C., Atroshi, I., Ekdahl, C., Johnsson, R., & Ornstein, E. (2003). Chronic upper extremity pain and co‐occurring symptoms in a general population. Arthritis Care & Research: Official Journal of the American College of Rheumatology, 49(5), 697-702.
[2] Almomani, F., Alghwiri, A. A., Alghadir, A. H., Al-momani, A., & Iqbal, A. (2019). Prevalence of upper limb pain and disability and its correlates with demographic and personal factors. Journal of Pain Research, 12, 2691–2700. https://doi.org/10.2147/JPR.S198480
[3] Badley EM, Tennant A. Changing profile of joint disorders with age: findings from a postal survey of the population of Calderdale, West Yorkshire, United Kingdom. Annals of the Rheumatic Diseases 1992; 51: 366-371.
[4] Park, S.-A., & Shoemaker, C. A. (2009). Observing Body Position of Older Adults While Gardening for Health Benefits and Risks. Activities, Adaptation & Aging, 33(1), 31–38. https://doi.org/10.1080/01924780902718582
[5] Martolia, D., Gupta, R., & Chhuneja, N. K. (2024). A study on prevalence of hand discomfort among the gardeners.
[6] R. J. Bancroft, T. McDonough, J. Shakespeare, and K. Lynas, “Orthotics,” European Geriatric Medicine, vol. 2, no. 2, pp. 122–125, Apr. 2011, doi: https://doi.org/10.1016/j.eurger.2010.07.006.

[7]M. R. Tucker et al., “Control strategies for active lower extremity prosthetics and orthotics: a review,” Journal of NeuroEngineering and Rehabilitation, vol. 12, no. 1, Jan. 2015, doi: https://doi.org/10.1186/1743-0003-12-1.

[8] M. Joseph, R. Constant, M. Rickloff, A. Mezzio, and K. Valdes, “A survey of client experiences with orthotics using the QUEST 2.0,” Journal of Hand Therapy, vol. 31, no. 4, pp. 538-543.e1, Oct. 2018, doi: https://doi.org/10.1016/j.jht.2018.07.002.
[9] Patel, P., & Gohil, P. (2022). Custom orthotics development process based on additive manufacturing. Materials Today: Proceedings, 59, A52–A63. https://doi.org/10.1016/j.matpr.2022.04.858
[10] R. Mendaza-DeCal, S. Peso-Fernandez, and J. Rodriguez-Quiros, “Orthotics and prosthetics by 3D-printing: Accelerating its fabrication flow,” Research in Veterinary Science, vol. 162, p. 104960, Sep. 2023, doi: https://doi.org/10.1016/j.rvsc.2023.104960.

[11] Y. Xu et al., “Design of personalized cervical fixation orthosis based on 3D printing technology,” Applied Bionics and Biomechanics, vol. 2022, pp. 1–8, Apr. 2022. http://dx.doi.org/10.1155/2022/8243128
[12] Bulbrook, K. (2021). Improving Gardening for People with Arthritis. https://appliedtechnology.humber.ca/assets/files/industrial-thesis-2021/kristie-bulbrook/Kristie%20Bulbrook%20thesis.pdf
[13] D. Tarnita, M. Catana, N. Dumitru, and D. N. Tarnita, “Design and Simulation of an Orthotic Device for Patients with Osteoarthritis,” Mechanisms and machine science, pp. 61–77, Nov. 2015, doi: https://doi.org/10.1007/978-3-319-23832-6_6.
[14] Cognitive Market Research, “Wrist Hand Orthoses Market Analysis 2026, Market Size, Share, Growth, CAGR, Forecast, Trends, Revenue, Industry Experts, Consultation, Online/Offline Surveys, Syndicate Reports,” Cognitive Market Research, 2023. https://www.cognitivemarketresearch.com/wrist-hand-orthoses-market-report (accessed Feb. 05, 2026).
[15] Verified Market Reports, “Wrist Supports Market Trends 2025 in United States | Growth Drivers & Industry Insights,” Verified Market Reports, Jun. 25, 2025.
https://www.verifiedmarketreports.com/product/wrist-supports-market/ (accessed Feb. 05, 2026).
[16] T. Pendergast, “Assistive Devices for Arthritis of the Hands: Protecting Your Joints,” Hospital for Special Surgery, Jan. 02, 2025. https://www.hss.edu/health-library/conditions-and-treatments/assistive-devices-for-the-hand-small-joint-protection
[17] “The Paexo wrist: efficient & innovative exoskeleton!,” Exoskeletons.com, Nov. 26, 2025. https://www.exoskelette.com/en/exoskeletons/paexo-wrist/ (accessed Feb. 05, 2026).
[18] “ACE Deluxe Wrist Brace | 3M United States,” Acebrand.com, 2026.
https://www.acebrand.com/3M/en_US/p/d/b00003387/ (accessed Feb. 05, 2026).
[19] “Good Grips Twist Jar Opener with Base Pad by OXO : comfort grip handle,” The
Wright Stuff, Inc. | ArthritisSupplies.com, 2026. https://www.arthritissupplies.com/good-
grips-twist-jar-opener-oxo.html (accessed Feb. 05, 2026).
[20] “Strap Wrench,” Homedepot.com, 2026. https://www.homedepot.com/p/Husky-6-in-Rubber-Strap-Wrench-410-273-0111/332221232 (accessed Feb. 05, 2026).
[21] “PenAgain Ergo-Sof Grip,” Performancehealth.com, 2018. https://www.performancehealth.com/penagain-ergo-soft-grips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 (https://www.performancehealth.com/penagain-ergo-soft-grips) (accessed Feb. 05, 2026).
[22] Roberto Francesco Pitzalis, D. Park, D. G. Caldwell, G. Berselli, and J. Ortiz, “Stat of the Art in Wearable Wrist Exoskeletons Part II: A Review of Commercial and Research Devices,” Dec. 2023, doi: https://doi.org/10.20944/preprints202311.0864.v2.
[23] “Amazon.com,” Amazon.com, 2025. https://www.amazon.com/Compression-Arthritis-Arthritic-Rheumatoid-Osteoarthritis/dp/B001GAOHSY (accessed Feb. 05, 2026).
[24] “Stainless Steel Utility Tongs,” Homedepot.com, 2026. https://homedepot.com/p/KitchenAid-10-28-in-Stainless-Steel-Utility-Tongs-KO091OHSSA/320434476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 (https://homedepot.com/p/KitchenAid-10-28-in-Stainless-Steel-Utility-Tongs-KO091OHSSA/320434476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) (accessed Feb. 05, 2026).
[25] “Wrist Exoskeletons | Exxovantage,” Exxovantage, 2024.
https://www.exxovantage.com/wrist-exoskeletons (accessed Feb. 05, 2026).
[26] RCIA. “RCAI Wrist Drop Orthosis.” MedStorz, 2026, medstorz.com/rcai-wrist-drop orthosis/. Accessed 22 Feb. 2026.
[27] IPESEMIS, “Hands,” TurboSquid, https://www.turbosquid.com/3d-models/hands-3d-1961009?dd_referrer= (accessed Feb. 29, 2026).
[28] “Peak Design Plate,” Printables.com, 2023. https://www.printables.com/model/578419-peak-design-plate/files (accessed Apr. 19, 2026).
[29] “Tripod adapter for Peak Design plate v3,” Printables.com, 2024. https://www.printables.com/model/225250-tripod-adapter-for-peak-design-plate-v3/files (accessed Apr. 19, 2026).

## Appendix A. Evidence of Brainstorming

1. Discovering intended use/users.

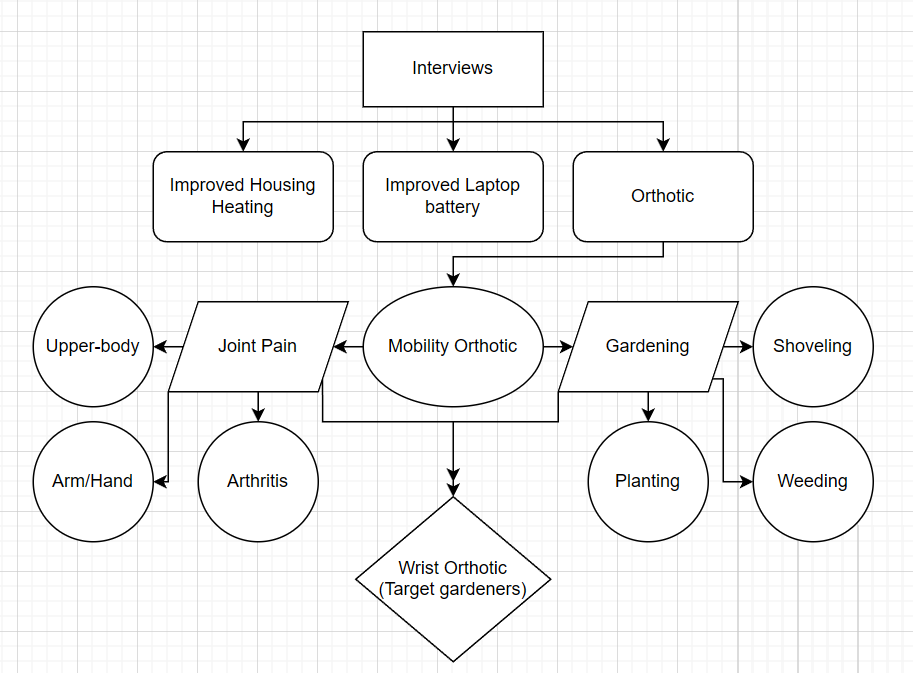
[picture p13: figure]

Figure 6. Discovering Intended User/Users Flow Chart

### 2. Brainstorming Notes:

- Research half about how to build/design, half about joint pain/mobility
- Each person finds 3 sources for the table
- Magnets / Quick-release systems to switch out accessories, Velcro, adjustable rods
Overall product idea: gardening mobility aid for arm with force boost mechanism

### 3. Design Feedback:

- Cost for a customized wristband
- Creating an elastic band with a magnet inside that can attach/slip onto tools --> can connect to a magnet on the glove
- Easier to use Velcro that twist knobs (?)
- Swivel on tool attachment

### 4. Device Concepts:

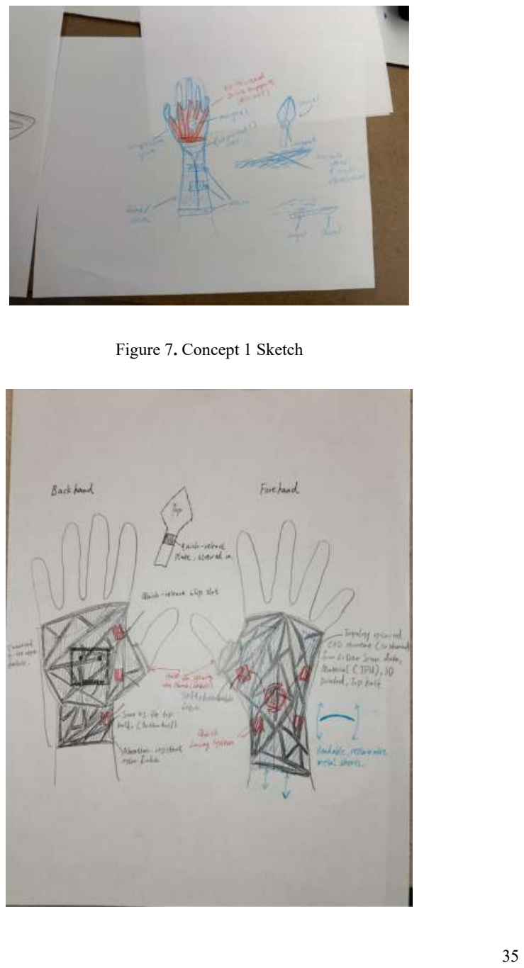
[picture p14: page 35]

Figure 7. Concept 1 Sketch

Figure 8. Concept 2 Sketch

Figure 9. Concept 3 Sketch

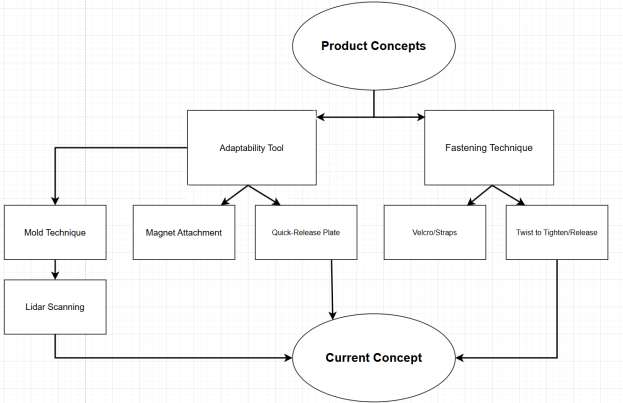
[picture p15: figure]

Figure 10. Team’s Product Concept/Idea

### 1. Grand Concept Design

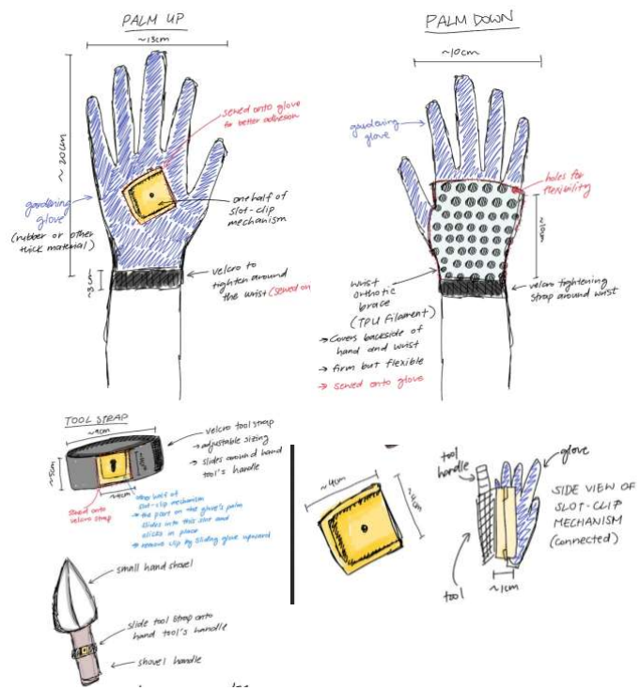
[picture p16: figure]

Figure 11. Updated Sketches of Grand Concept Design

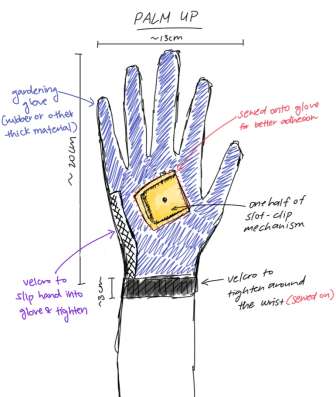
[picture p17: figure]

Figure 12. Updated Sketch of Wrist Orthosis with Velcro on Side of Glove

## Appendix B. Research Methodologies

Interview 1:

1. Can you tell me a little bit about yourself (age, ethnicity, gender, education, socio-economic status, ability, household make-up, etc.)?
a. Indian American female, age 50, mother of two, “empty nester”, college education, married
2. What do you do for a living?
a. Stay at home mother for the past 18 years
3. What are some of your hobbies?
a. Gardening, sewing, DIY projects, interior decorating
4. What does your typical day look like? What are some tasks you perform throughout your daily routine?
a. Cook for family, clean/organize the house, walk the dog, garden in the front and backyard
5. What are some products you use regularly in your daily tasks and hobbies?
a. Paper towels, shovels, watering can, pots/pans, spatulas, laptop, phone
6. Can you describe some things that bother or frustrate you when performing your routine tasks?
a. Chronic joint pain due to tennis elbow and arthritis, consistent pain in wrists
7. Is there anything that would make it easier or more enjoyable to perform these tasks?
a. A kind of brace or product that could put less strain on arms when gardening
8. Of the problems/frustrations/pains you’ve described, are there any that really stand out?
a. Why is this a significant problem?
i. Weeding is difficult because plants must be reached from the roots, but this puts pressure on the joints and causes more pain
b. What are you currently doing to alleviate this problem?
i. Taking pain medication, using home remedies/ointments
c. What do you like about how you currently handle this problem?
i. Easier to work after ingesting medication/resting
d. What isn’t working about how you currently handle this problem?

i. Can’t be efficient about the weeding, needing to take excessive breaks, strenuous on the arms and lots of pain afterward
e. What products do you wish existed that currently do not?
i. Some sort of arm brace that can keep arm steady and/or a tool that can reach the roots of small weeds without needing to overuse wrists/elbow

Summary:

The interviewee is a female of age 50 who is a stay-at-home mother of two children that currently attend college. She is married, has a college level education, and has previous work experience. In the interview, she said her hobbies include gardening, sewing, and craft DIY projects. We discussed what her typical day looks like and whether anything bothers her when working on her hobbies or daily tasks, to which she stated that her chronic joint pain stemming from arthritis and tennis elbow cause severe pain along her arm when she gardens outside. When asked about specific products she would find useful to her problem, she responded that a brace or structural support item would help her with weeding, which requires her to reach the root of the plant and is one of the more difficult aspects of gardening and a large contributor to her pain. Additionally, she mentioned that a tool that could reach the weeds’ roots without requiring her reach as far would be beneficial. The interview went well, as I received good information about a potential problem many people would have, and therefore a starting point for product brainstorming.

Figure 13. Interview 1 Analysis

Interview 2:

Getting to know your user (~5 mins)

1. Can you tell me a little bit about yourself (age, ethnicity, gender, education, socio-economic status, ability, household make-up, etc.)?

The user is a woman in her 50s who has tennis elbow and arthritis.

Task: Weeding the vegetable garden
Pains:
- It can be extremely painful to pull a large number of weeds.
- It is difficult to reach the roots of the weeds buried in the soil.
- It is often necessary to take many breaks and take pain relief medication excessively.

Task: Managing clutter and organization
Pains:
- It is costly to keep buying organizing shelves
- There is a lot of clutter to organize on a daily basis
- It is difficult to keep things in the same place and remember where the items are

- I am Enid, a sixty-year old woman who works in publishing, that now works remotely from home.
2. What do you do for a living?
- I am an executive in publishing children’s books.
3. What are some of your hobbies?
- I like to garden, run, cook, birdwatching, and going to antique stores.
4. What does your typical day look like? What are some tasks you perform throughout your daily

routine?

- I wake up around 5:30 in the morning, clean the kitchen and make coffee for myself, I plan my day while I drink my coffee. I then stoke the fireplace to heat the house and check into work on my computer, and I try to clean at least one room a day, generally trying to keep the house clean throughout the week. Since I recently moved to an older home, I am currently in the process of renovating and decorating it in recency as well.
5. What are some products you use regularly in your daily tasks and hobbies?
- I use all-purpose cleaners for the house, I use wood oil for the floors, I use a Shark vacuum and robot vacuum for the carpets, I use my laptop/iPad for work as well as an Eero router for Wi-Fi., and I also use a coffee maker for my coffee.

User Experiences (~10 mins)

6. Can you describe some things that bother or frustrate you when performing your routine tasks?
- I get frustrated with Wi-Fi issues in general as we live in a more rural community, I also run into issues with our robot vacuum as it gets stuck frequently and doesn’t properly map the house to reach optimal cleaning locations. I also have problems with our hot water is it takes at least 5 minutes to heat up, making cleaning and cooking take longer. More recently I have had trouble with our coffee maker as it doesn’t properly grind the beans fine enough most of the time.
7. Is there anything that would make it easier or more enjoyable to perform these tasks?
- What would make heating the house and improving insulation easier would be to get a new heating system for the house so that a fire doesn’t need to be stoked every so often. A solution for my coffee maker would be getting a new coffee maker or a separate coffee grinder to ensure that the coffee powder is fine enough for my daily brew.
8. Do any of the products you use lack certain features or could those products be improved?

- What would be improved is our heating system, our Wi-Fi, my robot vacuum and the coffeemaker.
9. Thinking about your hobbies, is there anything that you find difficult or don’t enjoy?
- I do not enjoy cleaning out our pond, I also do not enjoy clearing our land from ivy and brush as it grows too much and becomes difficult to trim especially in the winter with all the snow.
10. Of the problems/frustrations/pains you’ve described, are there any that really stand out?
- Heating
a. Why is this a significant problem?
- The issues with the heating affect a bunch of things around the house, causing issues with our piping and making morning showers and the use of hot water in general just take longer.
b. What are you currently doing to alleviate this problem?
- I am planning on getting a professional to evaluate what must be done to improve the heating, possibly having to buy baseboard heaters and replace our fireplace.
c. What do you like about how you currently handle this problem?
- I enjoy the comfort of the fireplace that we currently use and it makes the room that it’s located in a much more relaxing area.
d. What isn’t working about how you currently handle this problem?
- The fireplace doesn’t sufficiently heat the entire house enough, only really heating the first floor.
e. What products do you wish existed that currently do not?
- I wish that there was a historically sensitive heating system that would be both efficient and aesthetically pleasing in a much older house with exposed beams and that sort.

Summary

To identify common issues and understand the “users” in an engineering task, Enid

was interviewed, she is a 60-year-old mother who works as an executive in publishing for

children’s books. Enid is an active person who loves to garden, run, cook, and birdwatch in

her free time. She recently moved to an older rural farm which is the biggest frustration for

her with furnishing and fixing it up. Revealed in the interview is that daily, Enid wakes up early, makes her coffee and cleans the house, aiming to clean at least one room a day to

maintain a tidy living space. She also stokes the fire every morning before checking into

work on her computer and throughout the day to heat the house. The age of the house as

well as outdated appliances make her routine a bit more difficult in the morning she told,

as internet issues, problems with heating, as well as issues with the robotic vacuum and

the coffeemaker. Her biggest issue being that of the heating, thew fireplace not providing

sufficient heat for the entire houser, leaving some areas colder than others. Overall, the

interview was organized, well-paced and in the future recording the interview, with consent

allows me to review the interview and recite exactly what was said by the interviewee.

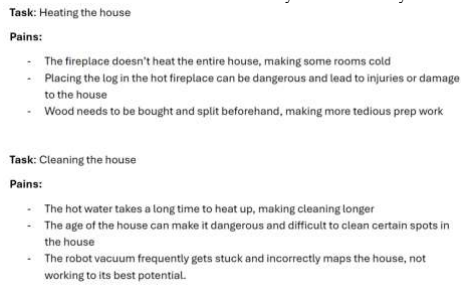
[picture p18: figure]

Figure 14. Interview 2 Analysis

Interview 3:

1. Can you tell me a little bit about yourself (age, ethnicity, gender, education, socio-economic status, ability, household make-up, etc.)?

I’m a 19-year-old first-year undergraduate student (Majoring in Computer Science) from China (an international student) and an only child.

2. What do you do for a living?

I’m a student who lives off my parents’ money.

3. What are some of your hobbies?

Playing badminton, working out, playing video games

4. What does your typical day look like? What are some tasks you perform throughout your daily routine?

After class, I do my homework and then play games. In the evening, I go to bed after working out. On weekends or holidays, I might play games all day or sleep all day.

5. What are some products you use regularly in your daily tasks and hobbies?

Using a computer (to play games) and using a badminton racket (to play badminton).

6. Can you describe some things that bother or frustrate you when performing your routine tasks?

Playing games or studying outside the dorm often results in insufficient battery life for my computer, which runs out of power easily. However, carrying a charger is too heavy.

7. Is there anything that would make it easier or more enjoyable to perform these tasks?

Bring a power bank; this will power your laptop and reduce the weight of carrying the charger.

8. Do any of the products you use lack certain features or could those products be improved?

Use batteries with higher energy density and chips with higher performance and lower power consumption for computers.

9. Thinking about your hobbies, is there anything that you find difficult or don’t enjoy?

My computer keeps crashing while I’m playing games, and the badminton rackets I rented from school are of very poor quality and very heavy.

10. Is there anything else that you find difficult or are unable to do, but wish you could?

My computer crashed, but I don’t know how to fix it or troubleshoot the problem (computer repair).

11. Of the problems/frustrations/pains you’ve described, are there any that really stand out? (Choose at least one)
a. Why is this a significant problem?

When a computer crashes, users don’t know how to handle it, leaving them without a computer to play games or study, thus delaying their learning/game progress.

b. What are you currently doing to alleviate this problem?

Learning some computer knowledge can alleviate or resolve these problems to some extent, thus preventing them from significantly impacting the user’s life.

c. What do you like about how you currently handle this problem?

Users can fix their computers without relying on others, while also saving potential computer repair expenses.

d. What isn’t working about how you currently handle this problem?

I haven’t learned enough and have limited resources, and I still can’t handle more complex computer problems on my own.

e. What products do you wish existed that currently do not?

Software that can automatically troubleshoot and resolve computer system/hardware problems, and a computer with long battery life and reliable performance.

Summary:

The user interviewed today isa 19-year-old male Chinese student currently a freshman majoring in Computer Science at Ohio State University. He is an only child and is currently fully supported by his parents. As a student living on campus, his daily life mainly consists of attending classes, doing homework, and then playing games or going to the gym/playing badminton after finishing his homework. On weekends or holidays, he might play games all day or sleep all day. He frequently uses his laptop for studying or playing games.
The main purpose of this interview was to understand Kevin's daily life and the difficulties he encounters with some of the products he frequently uses, such as his laptop and sports equipment. The interview went smoothly because the interviewer provided detailed and thoughtful answers, particularly regarding his laptop’s performance, malfunctions, and battery life. The focus of the interview was on the interviewee’s dependence on his computer, especially during study and gaming. The user also emphasized problems with his computer system (black screen/freezing) when gaming or studying. If a follow-up interview were conducted, I would need to further explore the emotional impact of these issues, and understand the specific frequency of these problems to better understand the user’s pain points, their severity, and persistence

Task 1: Using a laptop for studying and gaming outside the dorm

- Laptop battery life is insufficient, especially during extended use.
- Carrying the power adapter adds significant weight and is inconvenient.
- Laptop performance is unstable, and the system frequently crashes.

- When the laptop malfunctions, both studying and entertainment activities are inevitably delayed or interrupted.

Task 2: Leisure activities (playing games and badminton)

- Laptop freezing while gaming degrades the user’s gaming experience and affects game progress.
- Users lack the knowledge to independently diagnose and repair hardware and system problems.
- The badminton shuttlecocks provided by the school are heavy and of poor quality.
Interview | 4

Questions Asked and Answers:

Can you share some information about yourself such as your age, gender, and Education? I am a 53-year-old male with a high school education.

What do you do for work? I am a custodian at a high school.

What are some hobbies you enjoy? I enjoy fishing, hunting, and racing.

What does your typical day look like, and what are some tasks you perform in your daily routine? My day mostly consists of cleaning in which I sweep, vacuum, and mop 37
classrooms.

What are some objects or products that you may find yourself using in your daily life
Whether it's a task or a hobby? Backpack Sweeper, Chemicals, Fishing Poles, Guns.

User Experiences:

Can you describe any things that tend to bother or cause you to struggle when performing your daily tasks? When supplies aren’t stocked or where they are supposed to be, when equipment doesn’t work as it should, and faulty equipment.

Is there anything that could make those tasks easier or more enjoyable to perform? When equipment works properly without any hassle.

Do any products that you use to complete your tasks lack features or could be improved? Making things weighs less and making equipment easier to carry.

About your hobbies, is there anything you find difficult or unable to complete but wish
you could do so? Knee paid causes me issues; I wish I could climb or venture out further.

Is there anything you find a struggle or are completely unable to do in which you wish
you could?
I struggle with mobility; it would be nice to get around easier.

Of the struggles/frustrations that you’ve described in the previous questions, are there really any that stands out? Why is this a significant problem and what products
do you wish existed that currently do not? Primarily just equipment being lighter, but the
school | doesn’t | want | to | pay | for | better | equipment.

Description/Summary/List:

The interviewee was a 53-year-old man who works as a high school custodian who spends
most of his time either cleaning classrooms, or interacting with his hobbies which are fishing, hunting, and racing. The questions revolved around what he does and what problems he encounters when he's doing his tasks. Most of the problems he mentioned were about his lack of mobility as well as equipment that could be easier to carry in different ways. Overall, the team believes that the interview was a success but, in the future, the team could word the questions in a better format so it’s more interactive rather than just answering this and answering that. All around the team could just interact with them more and make it a more enjoyable experience for them.

Task: Carrying around equipment to numerous classrooms to clean

Pains:
- The equipment can be heavy, which causes physical stress and exhaustion.
- The equipment can be difficult to carry, which can relate to other things other than just the weight such as handles and if it’s awkward to carry.
- Equipment can be missing, not working, or faulty.

Task: Doing outside hobbies such as hunting and fishing.

## Pains:

- Movement restrictions due to previous injuries and joint pains.

- Arms and wrists are not working correctly due to overstressed joints, muscles, and bones.

## - Actions cannot be done as he wants because he is unable to do them

himself due to back pain and difficulty bending over.

## Appendix C. Prototype Working Drawing Packet

Figure 14. Quick Release Base Plate Drawing [28]

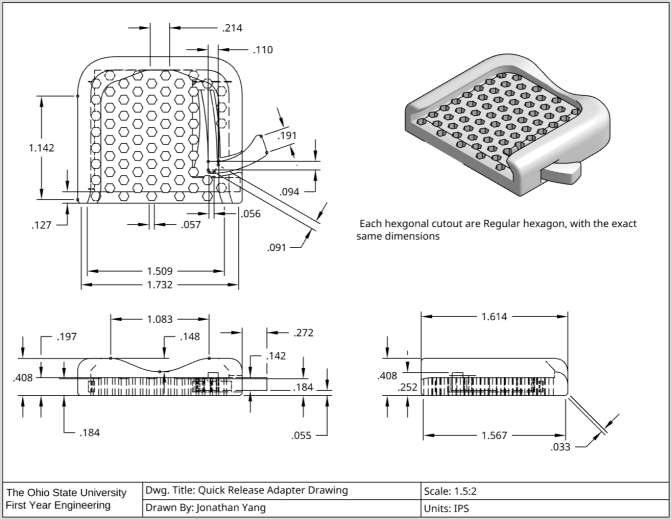
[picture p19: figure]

Figure 15. Quick Release Base Adapter Drawing [29]

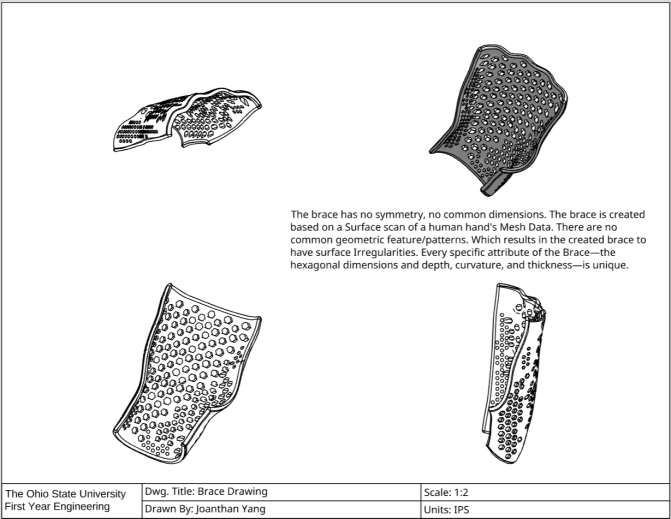
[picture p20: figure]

Figure 16. Quick Release Base Adapter Drawing

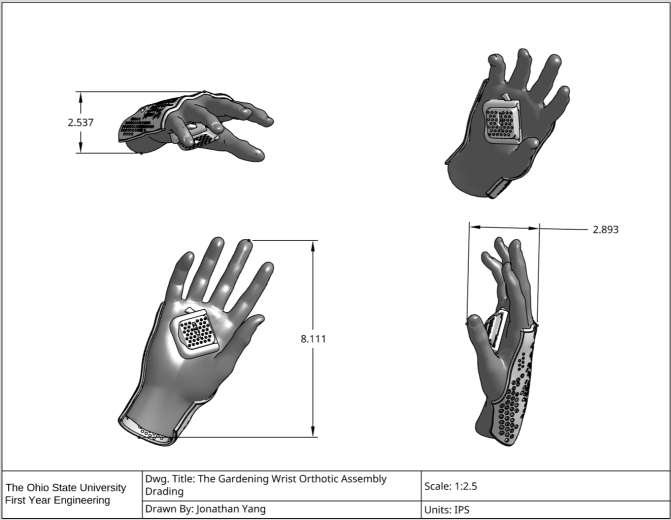
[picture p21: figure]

Figure 17. The Gardening Wrist Orthotic Assembly Drawing

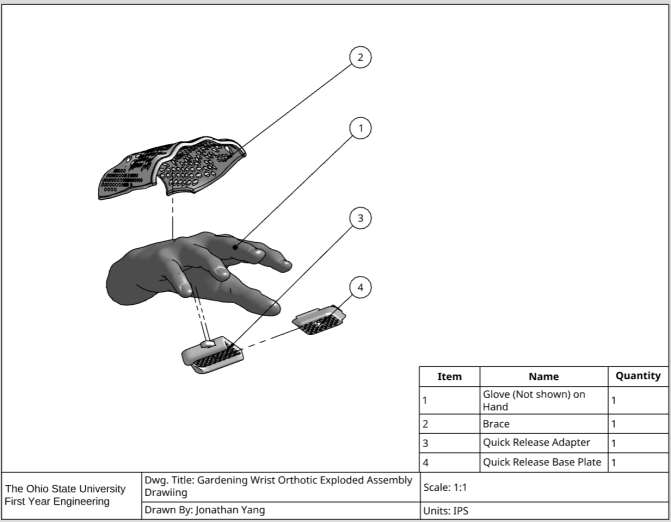
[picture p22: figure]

Figure 18. The Gardening Wrist Orthotic Exploded Assembly Drawing

## Appendix D. Additional Raw Data

OnShape Simulation Data:

Testing Day 1 Data:

Test | Data | Result
Slot clip speed | 4.3 seconds | Passed
Putting on orthosis speed | 8.65 seconds | Passed
Load bearing test | 25 lbs | Passed
Wrist extension test | -90 to 90 degrees | Passed
Weight test | 0.55 lbs | Passed

## Appendix E. Project Management Schedule and Meeting Minutes

Team N’s main goals and deliverables for this design project are given as a process; by specific deadlines, the team expects to fully CAD, print, assemble, and test the wrist gardening orthotic, ensuring that it meets all user needs and determined design requirements. Overall, the team’s mission is to complete a fully functional orthotic prototype that delivers on all intended applications.

### 2. Project Schedule

a. PERT Schedule

Figure 19. PERT Chart: Critical Path of Deliverables and Tasks

b. Gantt Chart

Figure 20. Gantt Chart: Schedule of Final Deliverables and Tasks

### 3. Prototyping Workday 1 Meeting Minutes

Meeting Minutes 1 – April 10, 2026, 3:55, 1182 Lab Hitchcock Hall 308, Riya, Jonathan, Nick

Objective statement: Purpose of the meeting was to begin assembling collected parts of the orthosis and update meeting.
Completed tasks:
- Original Gantt Chart and PERT chart finished
- Last 3d printing and EED store orders put in
- Materials collected
- Next meeting time established
- Riya: assemble the slot clip mechanism and Velcro strap for tool handle

Detailed Design Phase

SIMPLE GANTT CHART by Vertex42.com https://www.vertex42.com/ExcelTemplates/simple-gantt-chart.html

6 | 7 | 8 | 9 | 10 11 12 | 13 14 15 16 17 18 19 | 20 21 22 23 24 25 26 | 27 28 29 30 1 | 2 | 3 | 4 | 5 | 6 | 7 | 8 | 9 10 | 11 12 13 14 15 16 17
M | T | W | T | F | S | S | M | T | W | T | F | S | S | M | T | W | T | F | S | S | M | T | W | T | F | S | S | M | T | W | T | F | S | S | M | T | W | T | F | S | S
Documentation
R2 | Team N | 0% | 4/12/26 | 4/13/26
DD2 | Team N | 0% | 4/15/26 | 4/16/26
Prelim Verification Check-In | Team N | 0% | 4/15/26 | 4/16/26
DD3 | Team N | 0% | 4/19/26 | 4/20/26
FD1 | Team N | 0% | 4/22/26 | 4/24/26
FD2 | Team N | 0% | 4/22/26 | 4/27/26
FD3 | Team N | 0% | 4/22/26 | 4/27/26
FD4 | Team N | 60% | 4/22/26 | 4/27/26

Prototyping

CAD Model | Johnathon | 90% | 4/22/26 | 4/26/26
Order gardening gloves | Riya | 50% | 4/22/26 | 4/27/26
Pick up 3d prints and velcro | Dawson | 10% | 4/9/26 | 4/12/26
Sew Prototype | Nick | 0% | 4/11/26 | 4/12/26
Assemble prototype | Team N | 25% | 4/11/26 | 4/12/26
... | ... | 0% | 4/9/26 | 4/12/26
... | ... | 0% | 4/9/26 | 4/12/26

Meetings and Work Time

Prototyping Workday 1 MM | Team N | 30% | 4/27/26 | 5/2/26
Testing Day 1 | Team N | 0% | 5/3/26 | 5/8/26
Protyping Workday 2 MM | Team N | 0% | 5/9/26 | 5/14/26
Testing Day 2 | Team N | 0% | 5/15/26 | 5/19/26
Prototyping Workday 3 MM | Team N | 0% | 4/27/26 | 5/1/26
Testing Day 3 | Team N | 0% | 5/3/26 | 5/7/26
... | ... | 0% | 5/9/26 | 5/13/26

Phase start date: Mon, 4/6/2026

Apr 6, 2026 | Apr 13, 2026 | Apr 20, 2026 | Apr 27, 2026 | May 4, 2026 | May 11, 2026
TASK | ASSIGNED TO | PROGRESS | START | END

- Nick: sew brace onto gardening glove, add Velcro to wrist and side of the orthosis
- Jonathan: work on CAD model and collect 3d prints and orders
- Status: slot clip mechanism finished, brace 50% sewed onto glove, wrist tightening strap added

Tasks to be completed:

- Jonathan: Work on CAD model, put in new orders if needed
- Riya: Complete meeting minutes 1
- Team N: Update and work on the TDR
- Finalize scorecard & complete CATME evaluations

Project timeline (updated Gantt Chart):

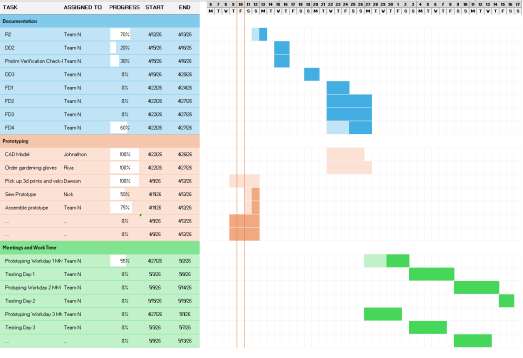
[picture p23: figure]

Figure 21. Updated Gantt Chart: Schedule of Final Deliverables and Tasks

Decisions:

- Team N will meet on April 11, 5pm at Thompson Library to continue assembling the prototype
- Finish CATME evaluations
- If needed, meet on Sunday to finish iteration 1 of prototype

### 4. Prototyping Workday 2 Meeting Minutes

Meeting Minutes 2 – April 20, 2026, 4:10 PM, 1182 Lab Hitchcock Hall 224, Jonathan

How did feedback from users influence your plan?

Users noted that securing tools via magnetic attachment could be constrained by the tools’ material and the strength of the magnetic; consequently, the team opted for a quick-release system design, which features a lower barrier to use and lower production costs.

Objective statement: Refine the appearance of the Gardening Wrist Orthotic, complete CAD Drawings/Simulations
Completed tasks:
- CAD Drawings/Simulations
- Refined the Gardening Wrist Orthotic
- Jonathan: Refine the appearance of the Gardening Wrist Orthotic, complete CAD Drawings/Simulations
- Status: Gardening Wrist Orthotic is fully competed (could expect possible minor adjustments in the future).

Tasks to be completed:

- Team N: FD1, FD2, Design Showcase Flyer
- Complete Final CATME evaluations

Project timeline (updated Gantt Chart):

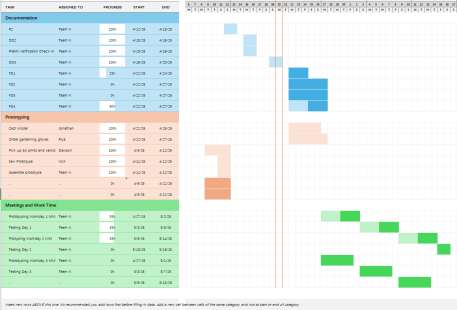
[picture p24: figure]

Figure 22. Updated Gantt Chart: Schedule of Final Deliverables and Tasks

Decisions:

- Finish Final CATME evaluations
- Finish the Design Showcase Flyer

## Appendix F. Team Working Agreement

Spring 2026
1/22/2026

### 1. Team Information

Course Section #7440
Team Designation: N
Elizabeth Jergens
Sneha Parthe

Contact Information:
Name | Email Address | Phone Number
Nicholas Farley | Farley.322@osu.edu | 908-499-8158
Riya Shankar | shankar.157@osu.edu | 510-309-8215
Jonathan Yang | Yang.8041@osu.edu | 765-767-3296
Dawson McMurry | mcmurry.25@osu.edu | 614-598-8588

### 2. Team Values & Goal

What are the team’s top values?
- Communication
- Responsibility
- Considerateness
What are the team’s expectations of quality level? Top goals? Minimum acceptable goals?
Include at least 1 goal regarding psychological safety, belonging, and inclusion.
- Our expectations for quality level is high, as we expect to put out the best work that we can as a team, our top goal being quality work in minimal time with our goal of turning assignments in on time to not back ourselves up. However, through it all, we want to prioritize respect and considerateness to each other, as a comfortable team is a cohesive team.

### 3. Communication and Meetings

What are your team’s preferred method(s) of contact and expected response time(s)? The team’s preferred method of contact is through the messaging group chat, and the expected response time (especially if one is directly addressed) is two hours.

How often do you plan on meeting to achieve your goals? (Do you anticipate this changing
throughout the semester?)
We plan on meeting once a week and having more meetings if necessary if more discussions need to occur within the team.

Primary and Secondary Meeting Day/Time/Location
Sunday 1/2pm, Thompson Library/RPAC

Individual(s) in charge of agendas, reminders, minutes
- Riya and Jonathan oversee reminders, Dawson is in charge of agendas, and Nick is in charge of minutes.

### 4. General Expectations and Group Norms

How are team members expected to behave? What are the group norms?
- Team members are expected to treat others with respect and with the intention of listening before speaking their opinion on a topic.

What are acceptable/unacceptable types of interaction?
- Acceptable interactions are those that show respect to one another and are formed in critical thinking and good intention. An unacceptable interaction is one that harms an individual mentally or physically, creating issues than resolutions.

What are team member expectations regarding attendance?
- Team members are expected to attend all meetings and classes unless external circumstances prevent it.

How are team members expected to behave during lab/class periods?
- Team members are expected to behave in a mature and positive manner throughout the labs and class, ensuring a safe and friendly collaborative environment.

What are team members meant to do between classes? Lab/class preparation?
- Team members are expected to complete all lab/class preparation if required, but even if not, mandatory it is in good practice to get all assignments done early.

How are team members meant to ensure the team stays on track?
- Staying on track means to get assignments done on time and in some cases early, ensuring that we are caught up to the task at hand.

How are documents expected to be shared?
- OneDrive

How many days before an assignment is due should everybody have their portion completed for review?
- 1 Day

When should team members first notify the group if they are struggling?
- Notify the team members immediately. When they are struggling, they should immediately contact fellow team members for support, and if an issue is out of the member’s hands, they can contact a faculty member or instructor for further help.

### 5. Individual Team Member Responsibilities

When/how will individual tasks/responsibilities be assigned?
- Individual tasks and responsibilities will be assigned through team communication. Team members can discuss and decide on the tasks/responsibilities they want to complete/undertake through group chat or before/after class discussions.

How will the team ensure work is fairly divided and that everyone participates equally?
- The team will communicate with other members to evenly split up the work, and everyone will have their own responsibilities that they will take ownership on.

Are there specific roles that all team members have?
- Every member of the team should be a leader in some way as when another member is struggling with their work or understanding an assignment, the team should be there for them to assist them throughout the way.

What specific tasks are team members in charge of?
- Team members are all respoble of completing their assigned work to the best of their ability and using all of their possible resources to ensure it will be sufficient work for the assignment.

How often will these roles/task rotate?
- Roles and tasks will be rotated and changed around each assignment, giving each member a chance at each position in a group.

### 6. Conflict Resolution

- Once the team goals, general member expectations, and individual team member responsibilities have been established, candid, non-threatening discussion must be held when the group or individuals are not meeting the agreed upon terms.

When there is disagreement amongst members, how will the team make decisions?

- The team will make decisions through a majority vote and active discussion about the topic of disagreement until a consensus is reached.
How will team members above be held accountable (be specific!)?
- Team members will be held accountable through direct addressing in the group chat or during in person meetings and members will be asked about their progress and results consistently to ensure that each member is working effectively.
How will team members that are not meeting expectations (not contributing to the team effectively) be
addressed?
- Team members that are not meeting expectations will be addressed in the group chat or when the team meets in person. Team members will not rush to accuse or judge and will begin simply by asking the addressed members about their current situation and whether they require help and finally discuss a resolution to the conflict.
How will team members that are not interacting appropriately with team members be addressed?
- Team members that are not interacting appropriately with other team members will be addressed first with empathy and respect to resolve any concerns. However, if the team member refuses to cooperate with the team, the team members will reach out to the instructional team for support.
How will the team handle resolving issues when a team member is not acting inclusively?
- When a team member is not acting inclusively, the team will handle resolving issues by first discussing possible confrontation plans together, then approach the team member that is not acting inclusively in a polite and diplomatic manner to understand the situation at hand and work together to come up with a plan to solve the issue. If this does not work, the team can ask for help from the instructional team.

What are the consequences for violating this agreement (be creative!)?
- The consequences for violating this agreement will be a notification sent to the instructor and/or TAs describing the conflict, how the team intended to approach and solve it, and the results of any discussions made between the team members and the member(s) they are in conflict with. The team will allow the instructional team to come up with potential consequences for the member’s actions.
When is it okay to redefine goals, expectations, and responsibilities?
- When the group starts to fall behind or work less efficiently, then goals and plans can be redefined. Doing so prevents group and grading conflicts as the group works with newly defined goals.
When will UTAs, GTAs, or the instructor become involved?
- UTAs, GTAs, or the instructor will get involved if an issue or question arises that cannot be resolved amongst the group. This ensures group cohesion and demonstrates proper resolution of any outstanding conflict.

### 7. Expectations of Faculty and GTAs

- If a team member fails to live up to this agreement, the situation may be reported to the staff, but the team will still be responsible for submitting a completed assignment. Staff will be available to meet with teams to resolve issues.

### 8. Team Signatures

Add a screenshot of your signature or digitally sign indicating that you have read and agree to all that is contained in this agreement.

______________________________________________
Nicholas Farley

______________________________________________ Jonathan Yang

______________________________________________ Riya Shankar

______________________________________________ Dawson McMurry

## Appendix G. Generative AI Prompts

Gemini – “Can you create a graphical persona, create a fictious name in which it is a relatively elderly woman who has a hobby in gardening; however, she isn't able to do the gardening well due to mobility and joint issues/pain. The race, education, occupation, doesn't matter for this scenario. The two main tasks that she does and has pains for are, 1. Weeding and Planting - Pains: Requires constant, forceful, use of hands and forearms. Often requires resting on the arms and elbows. It is difficult to reach the roots of the weeds buried in the soil. It is often necessary to take many breaks and take pain relief medication. Task 2: Digging and Turning Soil - Pains: Using shovels can put severe strain on the arms and joints. It can cause tendonitis & carpal tunnel syndrome from gripping tools tightly. Can strain the rotor cuff due to repetitive actions.”

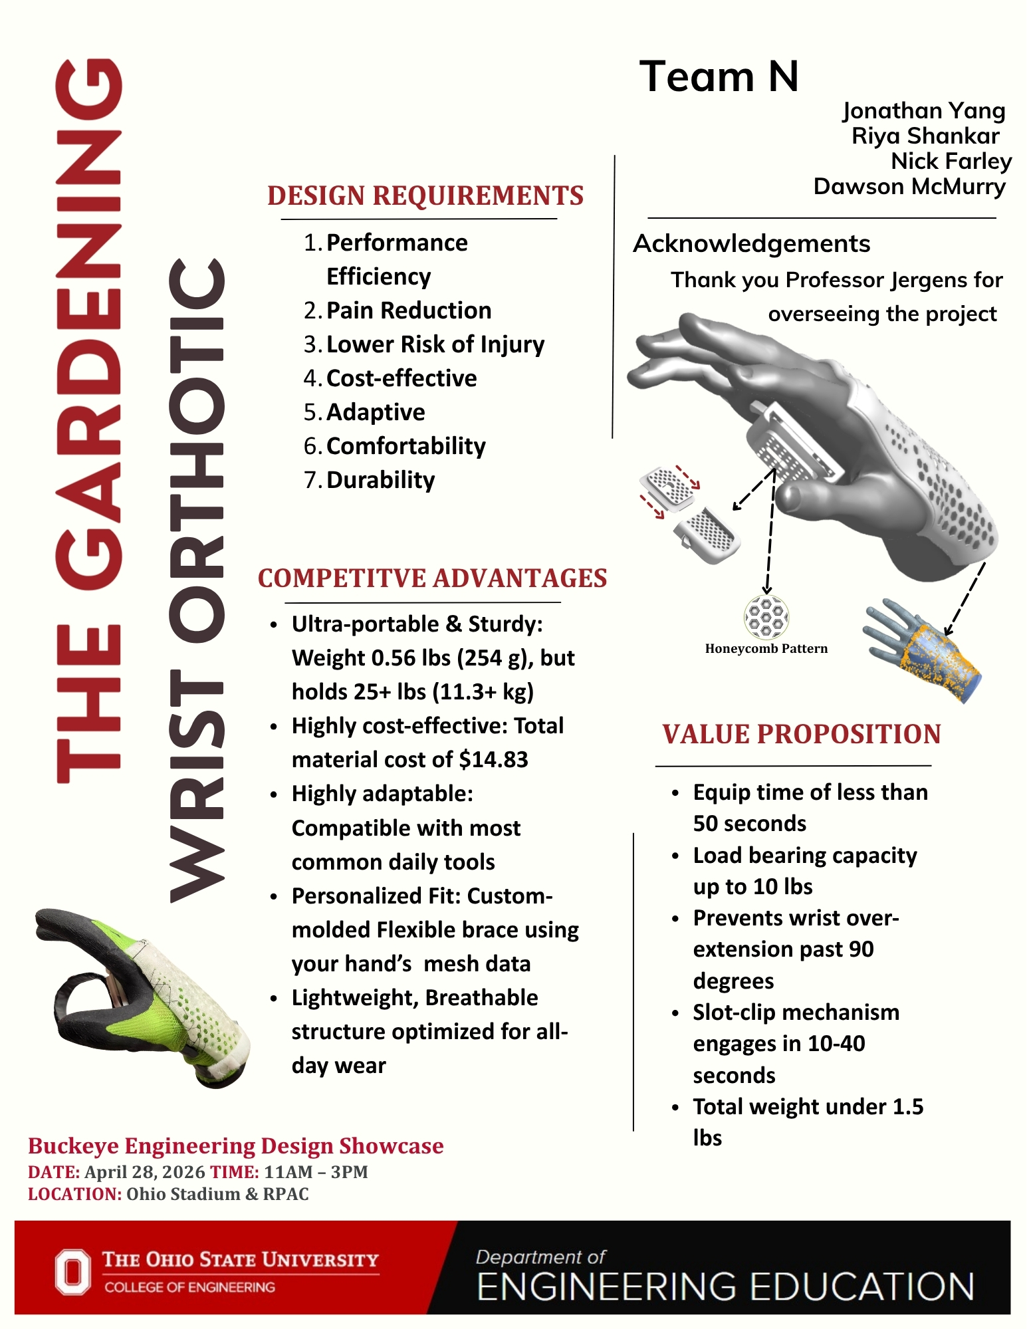
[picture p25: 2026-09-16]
media/Poster.jpg

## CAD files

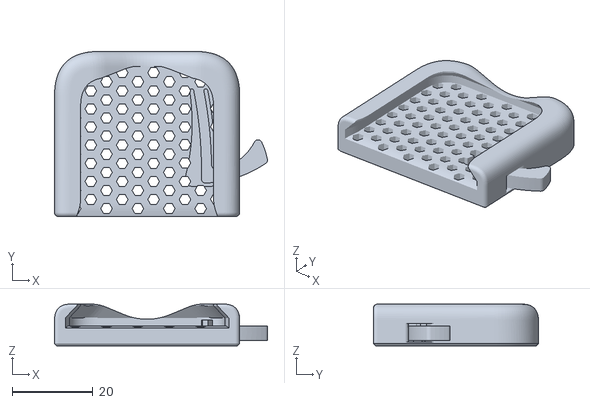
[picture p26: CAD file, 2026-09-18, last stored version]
Quick Release Adapter Holder.stl
52.9 x 41.0 x 10.4

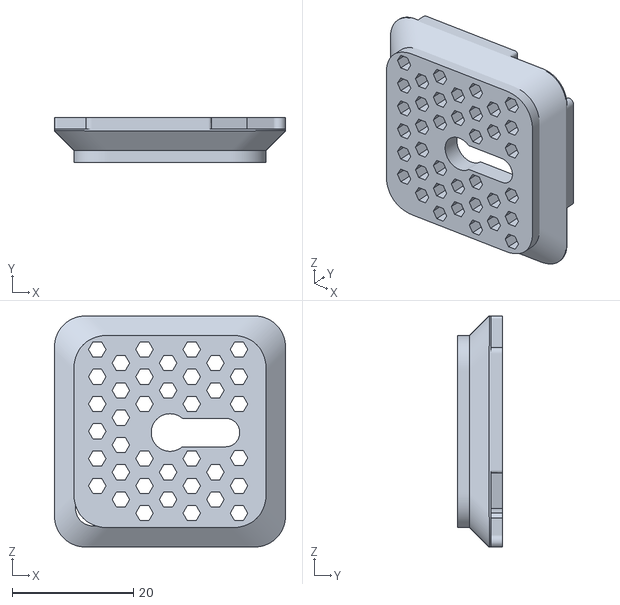
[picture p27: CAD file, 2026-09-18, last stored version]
Quick Release Adapter.stl
38.1 x 7.38 x 38.1

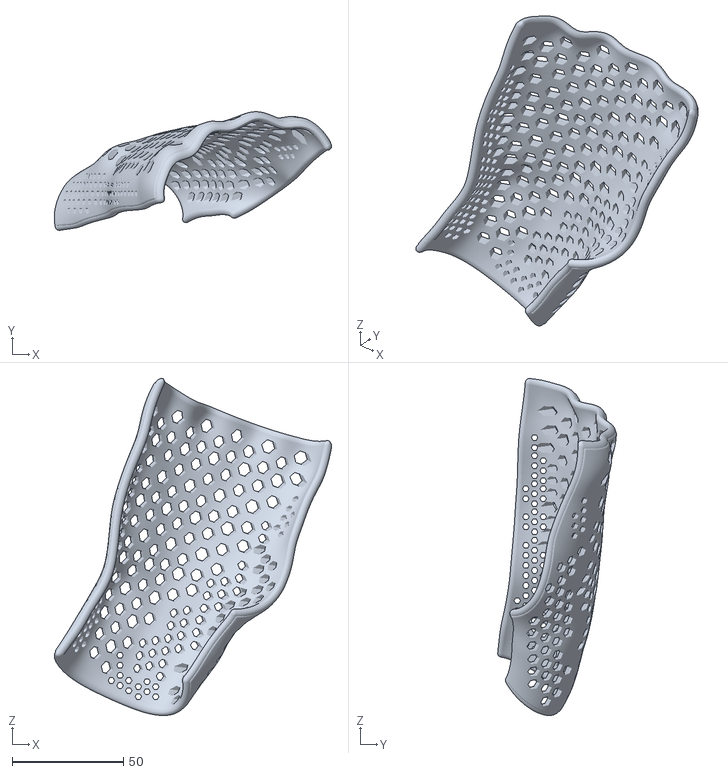
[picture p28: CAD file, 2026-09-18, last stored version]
Yang_8041_Support_Structure.stl
124.4 x 53.2 x 151.1

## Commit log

2026-09-16 更新 README.md
2026-09-18 Create CAD
2026-09-18 Revise 3D model links and CAD file information
    Updated links for 3D models and clarified CAD file location.
2026-09-18 Clarify access to CAD and 3D-print files
    Updated wording for clarity regarding CAD files.
2026-09-18 Update project description with showcase details
    Added details about the project's presentation at the Buckeye Engineering Design Showcase.
